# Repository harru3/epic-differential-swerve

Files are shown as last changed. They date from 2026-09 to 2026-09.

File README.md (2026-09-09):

# differential-swerve

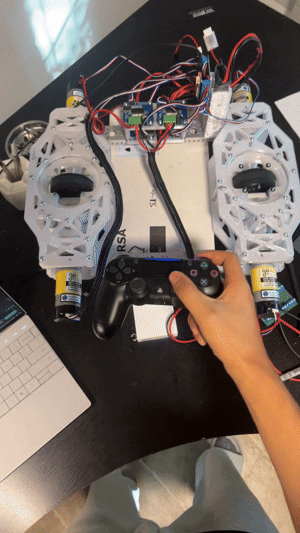
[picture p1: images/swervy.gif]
swerve swerving


# OVERVIEW:

This repo contains all the files for a fully 3D printed two-wheel differential swerve bot. All the parts can be sourced from Gobilda.com and Amazon, and it was made as a mini side project using spare parts from my FTC team, #23928 The Double Quarter Pounders. The current design runs off of 1150rpm motors for optimal acceleration/torque, but the geartrain can be edited to slot in any 4 spare motors you may have. 

Onshape link: https://cad.onshape.com/documents/e89bd9e2708e9aa3231597a3/w/33a491f01641b866d8c23332/e/f96b385fd39f2c792421a8a4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

The current code is configured to teleoperate the bot with a PS4 controller. 

# Parts:

Full BOM can be found as a PDF file in the repo files. Full cost is $540. Building it with spare motors is recommended, which brings it down to $320.

Most of the parts found in this assembly are fairly common FTC parts, so consider checking your stock before ordering.

# Extra:
Swerve pods can also play music (Aria Math by C418) by pressing left on the DPad. Works by modulating the PWM frequency.

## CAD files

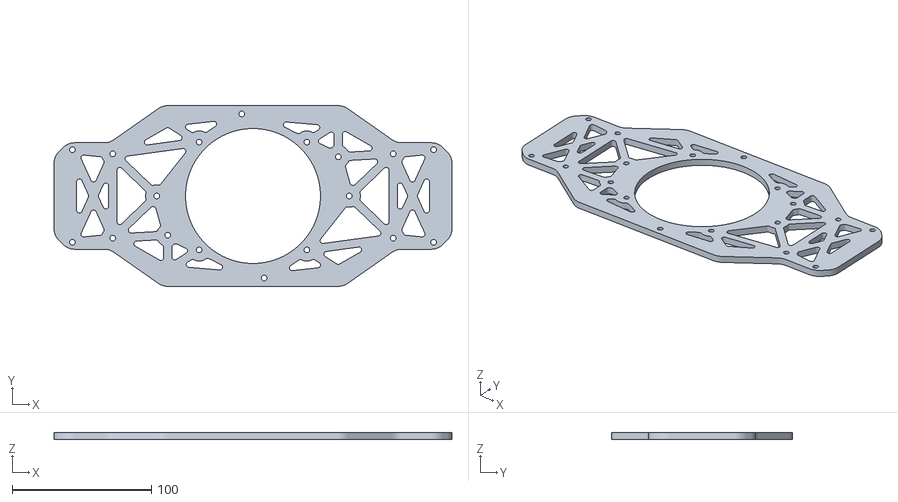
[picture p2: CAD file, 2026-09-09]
swerve_3DP_parts/base_plates_v2/base_plates_v2 - bottom_plate.stl
286.2 x 130.0 x 5.00

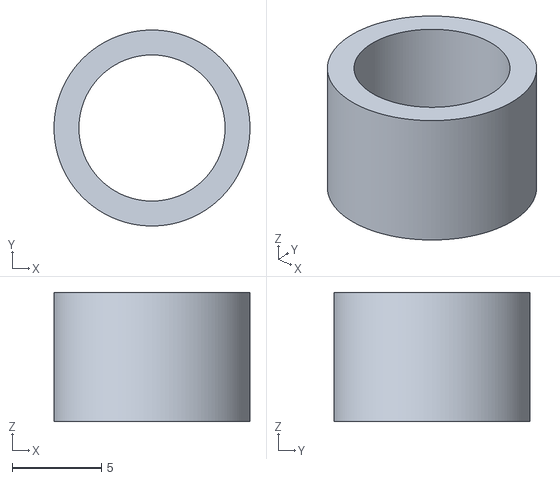
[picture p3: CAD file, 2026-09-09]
swerve_3DP_parts/geared_setup_m1.5/geared_setup_m1.5 - spacer_A.stl
11.0 x 11.0 x 7.25

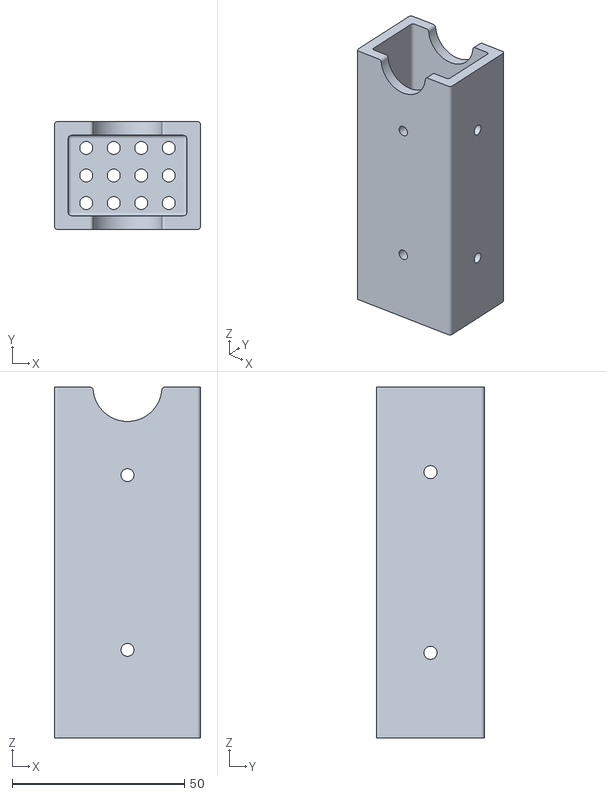
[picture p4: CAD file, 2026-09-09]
swerve_3DP_parts/misc parts/battery_case - battery_case.stl
42.5 x 31.4 x 102.0

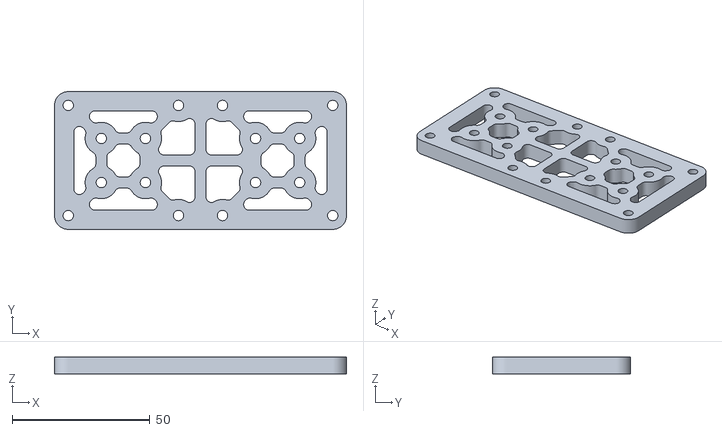
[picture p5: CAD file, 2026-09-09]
swerve_3DP_parts/motor_controller_panel/motor_controller_panel - bts7960_panel.stl
106.0 x 50.0 x 6.00

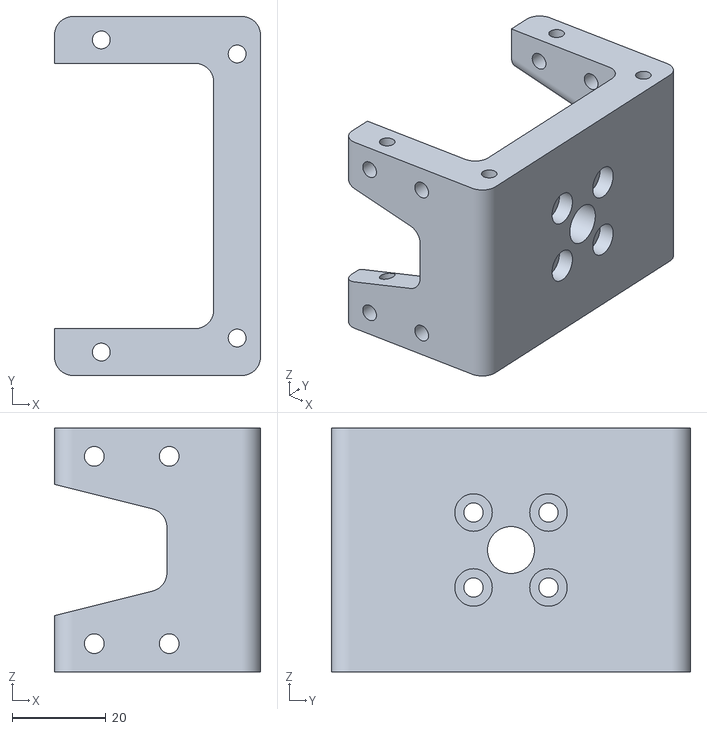
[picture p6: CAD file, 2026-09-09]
swerve_3DP_parts/base_plates_v2/base_plates_v2 - motor_mount.stl
44.0 x 76.6 x 52.0

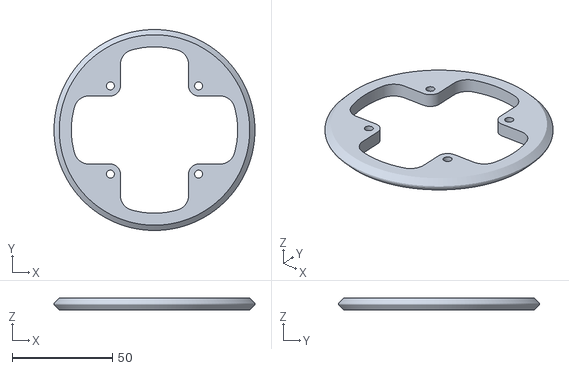
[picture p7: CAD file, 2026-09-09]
swerve_3DP_parts/geared_setup_m1.5/geared_setup_m1.5 - base_plate.stl
100.3 x 100.3 x 6.00

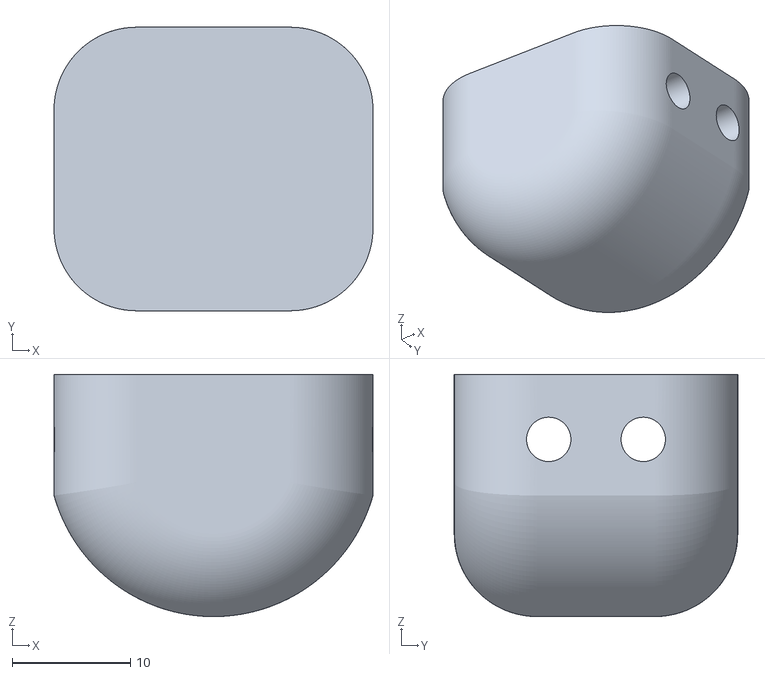
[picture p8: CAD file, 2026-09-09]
swerve_3DP_parts/misc parts/bottom_bumper - bumper.stl
27.0 x 24.0 x 20.5

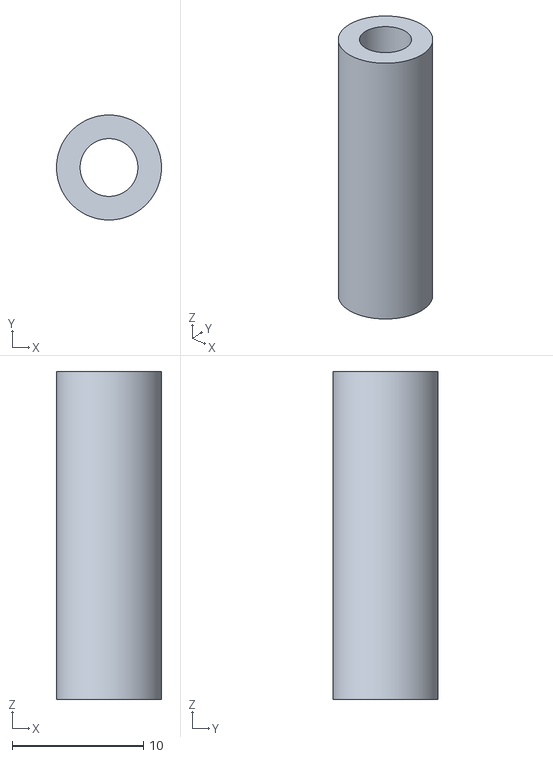
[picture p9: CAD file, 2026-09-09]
swerve_3DP_parts/motor_controller_panel/motor_controller_panel - long_spacer.stl
8.00 x 8.00 x 25.0

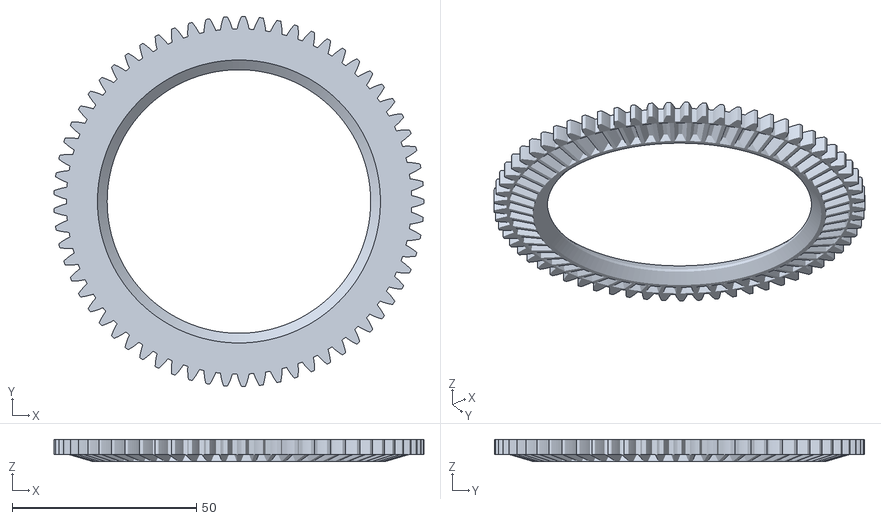
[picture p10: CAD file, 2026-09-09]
swerve_3DP_parts/geared_setup_m1.5/geared_setup_m1.5 - converter.stl
100.5 x 100.5 x 6.03

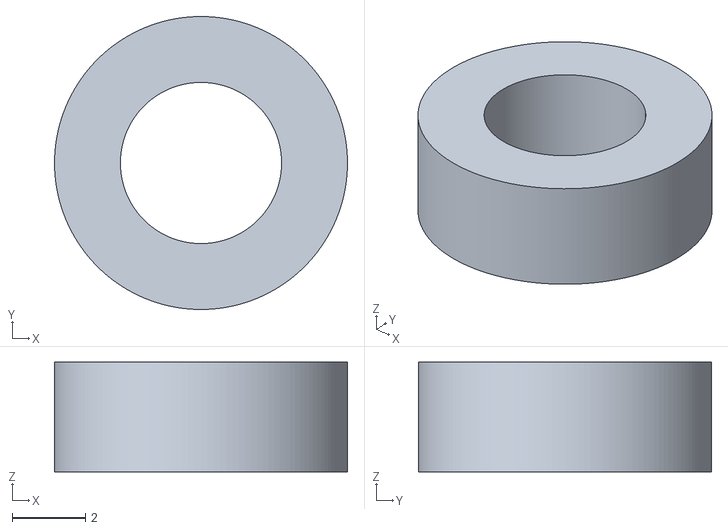
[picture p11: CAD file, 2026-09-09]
swerve_3DP_parts/motor_controller_panel/motor_controller_panel - short_spacer.stl
8.00 x 8.00 x 3.00

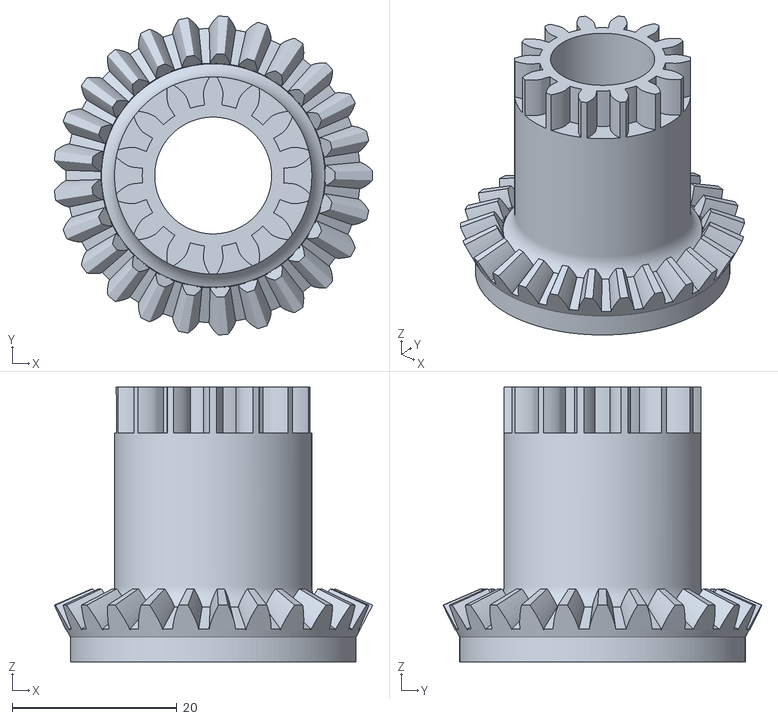
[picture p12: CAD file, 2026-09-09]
swerve_3DP_parts/geared_setup_m1.5/geared_setup_m1.5 - gear_B.stl
38.7 x 38.8 x 33.4

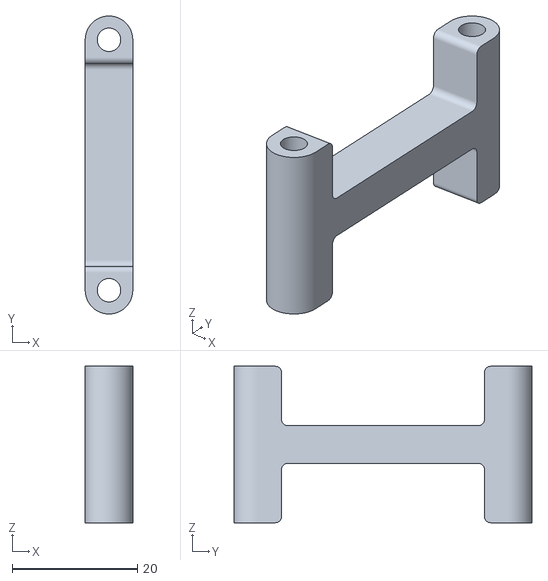
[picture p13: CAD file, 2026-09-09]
swerve_3DP_parts/motor_controller_panel/motor_controller_panel - h_spacer.stl
7.60 x 47.6 x 25.0

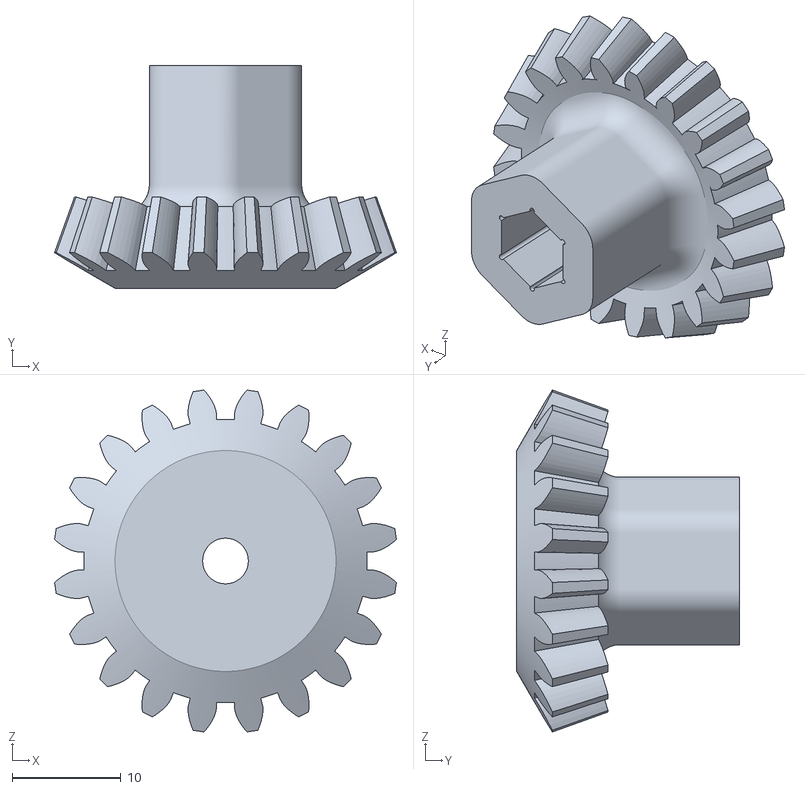
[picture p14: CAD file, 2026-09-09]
swerve_3DP_parts/geared_setup_m1.5/geared_setup_m1.5 - drive_gear.stl
31.5 x 20.5 x 31.5

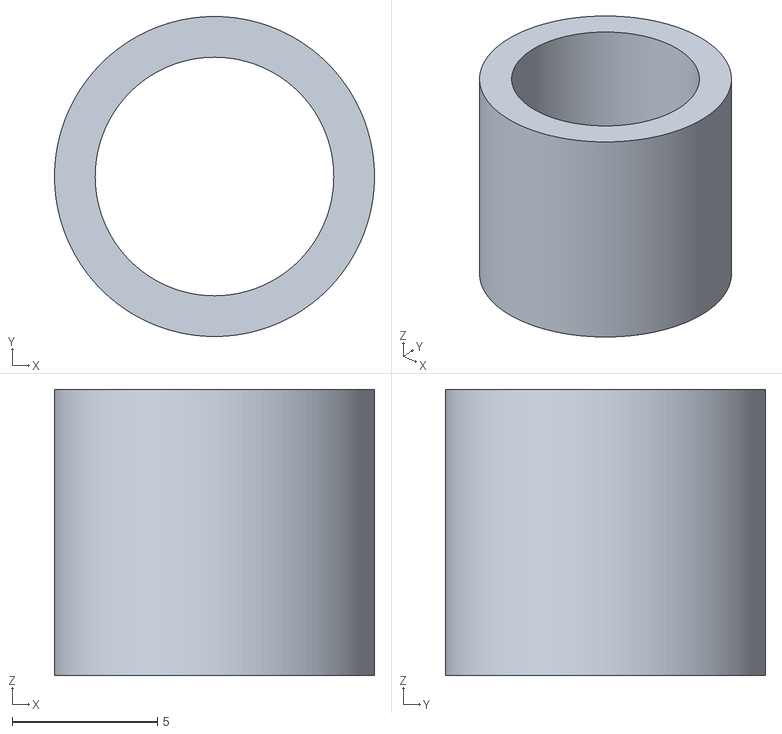
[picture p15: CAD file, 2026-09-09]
swerve_3DP_parts/geared_setup_m1.5/geared_setup_m1.5 - spacer_B.stl
11.0 x 11.0 x 9.84

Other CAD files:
swerve_3DP_parts/geared_setup_m1.5/geared_setup_m1.5 - bearing_holder.stl
swerve_3DP_parts/geared_setup_m1.5/geared_setup_m1.5 - gear_C.stl
swerve_3DP_parts/geared_setup_m1.5/geared_setup_m1.5 - gear_A.stl
swerve_3DP_parts/geared_setup_m1.5/geared_setup_m1.5 - spacer_A1.stl
swerve_3DP_parts/geared_setup_m1.5/geared_setup_m1.5 - spacer.stl

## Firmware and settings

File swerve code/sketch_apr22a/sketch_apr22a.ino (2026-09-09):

#include <PS4Controller.h>
#include "BluetoothSerial.h"
#include <elapsedMillis.h>

//song files
//#include "ariaMath.h"
#include "ariaMath2.h"

elapsedMillis musicTimer1;
elapsedMillis musicTimer2;
int intensity = 20;


int maxVel = 1400;
//A SIDE
#define A0_pw0 A0   //right blue
#define A0_pw1 A1   //left white
#define A0_enc0 A2  // blue
#define A0_enc1 A3  // white

#define A1_pw0 SCK   //right
#define A1_pw1 MOSI  //leftx
#define A1_enc0 TX   //blue
#define A1_enc1 RX   //white

//B SIDE
#define B0_pw0 13   //right
#define B0_pw1 12   //left
#define B0_enc0 27  // blue
#define B0_enc1 33  // white

#define B1_pw0 32   //right
#define B1_pw1 14  //leftx
#define B1_enc0 SCL   //blue
#define B1_enc1 SDA  //white

BluetoothSerial SerialBT;

// int rstick = 0;
// int lstick = 0;

elapsedMillis loopTimer;
float angleTargetA = 0.0;
float angleTargetB = 0.0;

// int vel = 0;
// elapsedMillis velTimer;


class Motor {
private:
  int pwm0;
  int pwm1;
  int enc0;
  int enc1;

  volatile long encoderCount;
  long lastEncoderCount;

  elapsedMicros lastVelRead;
  int lastPower = 0;

  elapsedMicros pidTimer;

public:
  //constructor
  Motor(int pwm0, int pwm1, int enc0, int enc1) {
    this->pwm0 = pwm0;
    this->pwm1 = pwm1;
    this->enc0 = enc0;
    this->enc1 = enc1;
    this->encoderCount = 0;
    this->lastEncoderCount = 0;
    //this->lastTime = 0;
  }

  void begin() {
    pinMode(enc0, INPUT_PULLUP);
    pinMode(enc1, INPUT_PULLUP);
    ledcAttach(pwm0, 20000, 8);
    ledcAttach(pwm1, 20000, 8);
  }

  //setting speed
  void setPower(double power) {
    //Serial.print(power);
    power = constrain(power, -255, 255);

    if (power < 10 && power > -10) {
      ledcWrite(pwm0, 0);
      ledcWrite(pwm1, 0);

    } else if (power > 0) {
      if (lastPower < 0) {  // delay to protect bridge from shorts
        ledcWrite(pwm1, 0);
        delay(1);
        ledcWrite(pwm0, (int)abs(power));
      } else {
        ledcWrite(pwm0, (int)abs(power));
      }
    } else if (power < 0) {
      if (lastPower > 0) {  // only delay on direction change
        ledcWrite(pwm0, 0);
        delay(1);
        ledcWrite(pwm1, (int)abs(power));
      } else {
        ledcWrite(pwm1, (int)abs(power));
      }
    }
    lastPower = power;
  }

  //update encoder readings
  void updateEncoder() {
    bool pinA = digitalRead(enc0);
    bool pinB = digitalRead(enc1);

    if (pinA == pinB) {
      encoderCount++;
    } else {
      encoderCount--;
    }
  }

  int getEncoderCount() {
    return encoderCount;
  }

  void resetEncoder() {
    encoderCount = 0;
  }

  float getVelocity() {
    float dt = (lastVelRead) / 1e6f;  // convert to seconds

    // Serial.print("dt: ");
    // Serial.print(dt);
    // Serial.print(" and the amount of couints inbetween: ");


    if (dt <= 0) return 0;

    long currentCount = encoderCount;
    // Serial.print(currentCount - lastEncoderCount);
    // Serial.print("  ");
    float velocity = (currentCount - lastEncoderCount) / dt;

    lastEncoderCount = currentCount;
    lastVelRead = 0;

    return velocity;
  }
};

class wheelController {
private:
  // References to physical motor objects
  Motor &motorLeft;
  Motor &motorRight;

  // Independent timers for each PID calculation loop
  elapsedMicros velocityTimer;
  elapsedMicros angleTimer;

  // Tracking variables for Integral errors to prevent windup
  float velocityIntegral = 0;
  float angleIntegral = 0;
  float lastVelocityError = 0;
  float lastAngleError = 0;

  float Kp_vel = 0.25;
  float Ki_vel = 0.0;
  float Kd_vel = 0.0;
  float Kf_vel = 0.36;

  float Kp_ang = 8.0;
  float Ki_ang = 0.0;
  float Kd_ang = 0.25;  //.25
  float Kf_ang = 0.0;

  float lastAngleTarget;

public:
  // Constructor grabs the real deal motors by reference using '&'
  wheelController(Motor &left, Motor &right)
    : motorLeft(left), motorRight(right) {}

  void update(float targetVelocity, float currentVelocity, float targetAngle, float currentAngle) {
    // 1. Calculate Velocity PID Output
    float dtVel = velocityTimer / 1000000.0;  // Convert to seconds
    velocityTimer = 0;
    float velOutput = calculateVelocityPID(targetVelocity, currentVelocity, dtVel);

    // 2. Calculate Angle PID Output
    float dtAng = angleTimer / 1000000.0;
    angleTimer = 0;
    float angOutput = calculateAnglePID(targetAngle, currentAngle, dtAng);

    // 3. Kinematic Mixing (The Blend)
    float powerLeft = velOutput + angOutput;
    float powerRight = velOutput - angOutput;

    const float MAX_POWER = 255.0;

    // 3. Find the maximum absolute power requested by either motor
    float maxRequested = max(abs(powerLeft), abs(powerRight));

    // 4. If we exceed limits, scale back ONLY the velocity component
    if (maxRequested > MAX_POWER) {
      // How much did we overflow?
      float overflow = maxRequested - MAX_POWER;

      // Reduce the velocity output directly by the overflow amount.
      // This perfectly shrinks the drive speed while keeping 'angOutput' untouched!
      if (velOutput > 0) {
        velOutput -= overflow;
      } else {
        velOutput += overflow;
      }

      // Recalculate safe, scaled powers
      powerLeft = velOutput + angOutput;
      powerRight = velOutput - angOutput;
    }

    //fitler and constrain
    powerLeft = constrain(powerLeft, -MAX_POWER, MAX_POWER);
    powerRight = constrain(powerRight, -MAX_POWER, MAX_POWER);


    // 4. Send the commands to the real hardware objects
    Serial.print(" L pow: ");
    Serial.print(powerLeft);
    Serial.print(" | R pow: ");
    Serial.print(powerRight);

    motorLeft.setPower(powerLeft);
    motorRight.setPower(powerRight);
  }



private:
  float calculateVelocityPID(float target, float current, float dt) {

    float error = target - current;

    // Serial.print(" Error: ");
    // Serial.print(error);

    velocityIntegral += error * dt;
    float derivative = (error - lastVelocityError) / dt;
    lastVelocityError = error;

    return (Kp_vel * error) + (Ki_vel * velocityIntegral) + (Kd_vel * derivative) + (Kf_vel * target);
  }

  float calculateAnglePID(float target, float current, float dt) {
    // CRITICAL: Handle angle wrapping (e.g., target 5 degrees, current 355 degrees)

    if (target != lastAngleTarget) {
      angleIntegral = 0;
    }

    lastAngleTarget = target;


    float error = target - current;
    if (error > 180) error -= 360;
    if (error < -180) error += 360;

    // Serial.print(" Error: ");
    // Serial.print(error);

    angleIntegral += error * dt;
    float derivative = (error - lastAngleError) / dt;
    lastAngleError = error;
    // Serial.print(" Intergral: ");
    // Serial.print(Ki_ang * angleIntegral);


    return (Kp_ang * error) + (Ki_ang * angleIntegral) + (Kd_ang * derivative) + (Kf_ang);
  }
};

float wheelVel(int vel0, int vel1) {
  return (vel0 + vel1) / 2.0;
}

float wheelAngle(int count0, int count1) {
  float angle = ((count0 - count1) / 1295.6) * 360.0;
  while (angle > 360) {
    angle = angle - 360;
  }
  while (angle < -360) {
    angle = angle + 360;
  }
  return angle;
}



Motor motorA0(A0_pw0, A0_pw1, A0_enc0, A0_enc1);
Motor motorA1(A1_pw0, A1_pw1, A1_enc0, A1_enc1);

Motor motorB0(B0_pw0, B0_pw1, B0_enc0, B0_enc1);
Motor motorB1(B1_pw0, B1_pw1, B1_enc0, B1_enc1);

wheelController wheelLeft(motorA0, motorA1);

wheelController wheelRight(motorB0, motorB1);



void motorA0ISR() {
  motorA0.updateEncoder();
}

void motorA1ISR() {
  motorA1.updateEncoder();
}

void motorB0ISR() {
  motorB0.updateEncoder();
}

void motorB1ISR() {
  motorB1.updateEncoder();
}

double stickAngle(double x, double y) {
  return atan2(y, x) * -57.2958;
}

double stickMagnitude(double x, double y) {
  if (abs(x) < 30) {
    x = 0;
  }
  if (abs(y) < 30) {
    y = 0;
  }
  return mapf(constrain(abs(sqrt(pow(x, 2) + pow(y, 2))), 0, 255), 0, 255, 0, 1);
}


float mapf(float x, float in_min, float in_max, float out_min, float out_max) {
  return (x - in_min) * (out_max - out_min) / (in_max - in_min) + out_min;
}

float deadband(float input) {
  if (abs(input) < 5) return 0.0f;
  return input;
}


void music(int song1[][2], int song1Len, int song2[][2], int song2Len) {
  static int song1Index = 0;
  static int song2Index = 0;
  //reset the song from beginning
  if (PS4.Left()) {
    song1Index = 0;
    song2Index = 0;
    musicTimer1 = 0;
    musicTimer2 = 0;
  }

  if (song1Index < song1Len) {
    //play note
    ledcChangeFrequency(A0_pw0, song1[song1Index][0], 8);
    ledcChangeFrequency(A0_pw1, song1[song1Index][0], 8);
    Serial.print(" note number: ");
    Serial.print(song1Index);

    //setting power to play
    if (song1[song1Index][0] != 0) {
      motorA0.setPower(intensity);
    } else {
      motorA0.setPower(0);
    }

    //wait for note to finish
    if (musicTimer1 > song1[song1Index][1]) {
      musicTimer1 = 0;
      song1Index += 1;
    }
  }

  if (song2Index < song2Len) {
    //play note
    ledcChangeFrequency(A1_pw0, song2[song2Index][0], 8);
    ledcChangeFrequency(A1_pw1, song2[song2Index][0], 8);
    Serial.print(" note2 number: ");
    Serial.println(song2Index);

    if (song2[song2Index][0] != 0) {
      motorA1.setPower(intensity);
    } else {
      motorA1.setPower(0);
    }

    //wait for note to finish
    if (musicTimer2 > song2[song2Index][1]) {
      musicTimer2 = 0;
      song2Index += 1;
    }
  }
  //setting power

  //resetting back to normal for driving and stuff once both songs finish
  if (song1Index >= song1Len) {
    ledcChangeFrequency(A0_pw0, 20000, 8);
    ledcChangeFrequency(A0_pw1, 20000, 8);
  }
  if (song2Index >= song2Len) {
    ledcChangeFrequency(A1_pw0, 20000, 8);
    ledcChangeFrequency(A1_pw1, 20000, 8);
  }
}


void setup() {
  Serial.begin(115200);
  SerialBT.begin("ESP32");
  Serial.println(SerialBT.getBtAddressString());
  PS4.begin("14:2b:2f:cd:7a:42");

  //PS4.begin("40:f5:20:45:22:8a");

  

  motorA0.begin();
  attachInterrupt(digitalPinToInterrupt(A0_enc0), motorA0ISR, CHANGE);

  motorA1.begin();
  attachInterrupt(digitalPinToInterrupt(A1_enc0), motorA1ISR, CHANGE);

  motorB0.begin();
  attachInterrupt(digitalPinToInterrupt(B0_enc0), motorB0ISR, CHANGE);

  motorB1.begin();
  attachInterrupt(digitalPinToInterrupt(B1_enc0), motorB1ISR, CHANGE);
}


void loop() {


  int rsticky = map(constrain(deadband(PS4.RStickY()), -120, 120), -120, 120, -255, 255);
  int rstickx = map(constrain(deadband(PS4.RStickX()), -120, 120), -120, 120, -255, 255);
  int lsticky = map(constrain(deadband(PS4.LStickY()), -120, 120), -120, 120, -255, 255);
  int lstickx = map(constrain(deadband(PS4.LStickX()), -120, 120), -120, 120, -255, 255);

  float l2 = mapf(PS4.L2Value(), 0.0, 255.0, 0.0, 1.0);


  int hertz = 20;
  int samplingRate = int(1000 / hertz);


  if (loopTimer > samplingRate && !PS4.L1()) {

    //LOW PASS FILTER
    float alpha = 0.35f;  // lower = smoother, more lag

    static float smoothed_ry = 0.0f;
    smoothed_ry = alpha * rsticky + (1.0f - alpha) * smoothed_ry;

    static float smoothed_rx = 0.0f;
    smoothed_rx = alpha * rstickx + (1.0f - alpha) * smoothed_rx;

    static float smoothed_l2 = 0.0f;
    smoothed_l2 = alpha * l2 + (1.0f - alpha) * smoothed_l2;

    static float smoothed_ly = 0.0f;
    smoothed_ly = alpha * lsticky + (1.0f - alpha) * smoothed_ly;

    static float smoothed_lx = 0.0f;
    smoothed_lx = alpha * lstickx + (1.0f - alpha) * smoothed_lx;

    static float sineMultiplier = 0.0f;
    sineMultiplier = sinf(radians( wheelAngle(motorA0.getEncoderCount(), motorA1.getEncoderCount())));

    static float velA = 0.0f;
    // velA = -maxVel * (stickMagnitude(smoothed_lx, smoothed_ly) + map(rstickx, -255, 255, -1, 1) );
    velA = -maxVel * (stickMagnitude(smoothed_lx, smoothed_ly) + map(rstickx, -255, 255, -1, 1) * sineMultiplier );

    static float velB = 0.0f;
    velB = -maxVel * (stickMagnitude(smoothed_lx, smoothed_ly) - (map(rstickx, -255, 255, -1, 1) * sineMultiplier ) );



    if (stickMagnitude(smoothed_rx, smoothed_ry) > 0.01) {
      angleTargetA = stickAngle(smoothed_rx, smoothed_ry);
    }

    if (stickMagnitude(smoothed_lx, smoothed_ly) > 0.01) {
      angleTargetB = stickAngle(smoothed_lx, smoothed_ly);
    }

    // Serial.print(l2 );

    Serial.print("wheelAngleA: ");
    Serial.print(wheelAngle(motorA0.getEncoderCount(), motorA1.getEncoderCount()));
    Serial.print("sine ");
    Serial.print( sineMultiplier );


    // Serial.print("  wheelAngleB: ");
    // Serial.print(wheelAngle(motorB0.getEncoderCount(), motorB1.getEncoderCount()));
    // Serial.print(" angletarget: ");
    // Serial.print(angleTarget);


    wheelLeft.update(velA, wheelVel(motorA0.getVelocity(), motorA1.getVelocity()),
                     angleTargetB, wheelAngle(motorA0.getEncoderCount(), motorA1.getEncoderCount()));

    wheelRight.update(velB, wheelVel(motorB0.getVelocity(), motorB1.getVelocity()),
                     -angleTargetB, wheelAngle(motorB0.getEncoderCount(), motorB1.getEncoderCount()));
    
    //tester

    // if(PS4.R1()){
    //   motorB1.setPower(255);
      
    // }else{
    //   motorB1.setPower(0);
      
    // }

    // Serial.print("Enc count: ");

    // Serial.print(motorB1.getEncoderCount());

    loopTimer = 0;
    Serial.println();
  }

  //tester
  


  if (PS4.L1()) {
    music(part2, noteCount, part1, noteCount);
  }

  //reset pwm
  if (PS4.Square()) {
    ledcChangeFrequency(A1_pw0, 20000, 8);
    ledcChangeFrequency(A1_pw1, 20000, 8);
    ledcChangeFrequency(A0_pw0, 20000, 8);
    ledcChangeFrequency(A0_pw1, 20000, 8);
  }
}
